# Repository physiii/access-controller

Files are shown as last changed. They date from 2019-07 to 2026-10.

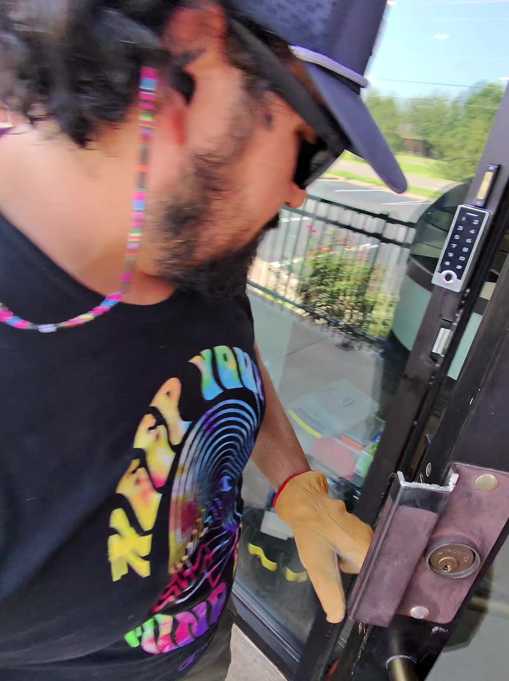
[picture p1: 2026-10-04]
images/20260725_door_keypad_strike_install.jpg

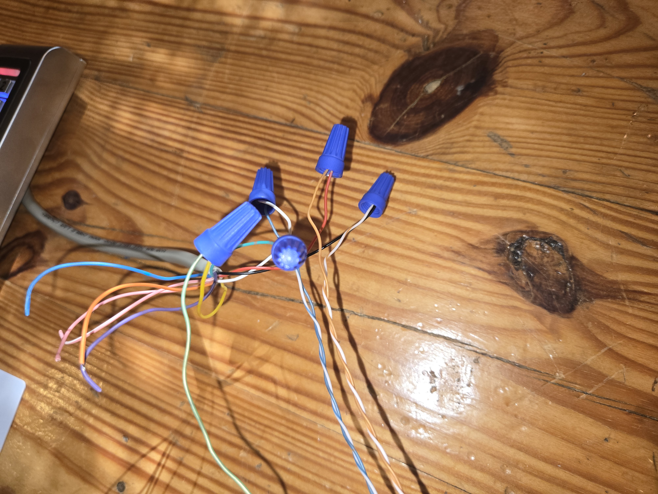
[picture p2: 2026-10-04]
images/20260709_174217.jpg

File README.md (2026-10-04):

# Access Controller

ESP32-S3 firmware, web controls and hardware for a two-channel strike/magnetic
lock controller. Wiegand readers, keypads, exit buttons, fobs and motion inputs
feed the same authorization and lock-control services.

## Project map

| Area | Purpose |
|---|---|
| [Active firmware](code/controller/README.md) | ESP32-S3 controller and embedded Device Manager UI |
| [Documentation](docs/README.md) | Architecture, hardware, provisioning and operating workflows |
| [Tests](code/controller/tests/README.md) | Offline checks and separately invoked device tests |
| [Tunnel server](code/tunnel/README.md) | Optional remote access to the device UI |
| [Controller mini](code/controller_mini/README.md) | Alternate experimental firmware |
| `circuits/controller`, `circuits/strike` | KiCad designs and manufacturing artifacts |
| `model`, `images` | Enclosures, mechanical sources and board views |
| [Bench photos](docs/hardware-bench-2026-07-24.md) | Recovered controller and keypad wiring views |
| [Consolidation audit](docs/WORKSPACE_CLEANUP.md) | Branch disposition, recovery and current verification |

```mermaid
flowchart LR
    Inputs["Wiegand / keypad / exit / fob / motion"] --> Rules["Authorization and automation"]
    Rules --> Locks["Two lock channels"]
    Web["Device Manager UI"] --> API["Local HTTP API"]
    API --> Rules
    API <--> Store["Stored credentials and configuration"]
    Gateway["Optional tunnel gateway"] <--> API
```

## Build and check

Use the configured ESP-IDF checkout and `esp_websocket_client` component.
The current firmware targets **ESP32-S3**; building does not flash a controller.

```sh
source ~/esp/esp-idf/export.sh
idf.py -C code/controller build
cd code/controller/tests
npm ci
npm run test:wiegand-format
npm run test:boot-audio
CHROMIUM_PATH=/usr/bin/google-chrome npm run test:ui-network
```

The browser check uses intercepted fixtures and cannot operate a real lock.
It covers desktop/mobile navigation, AP/STA links and recovery after saving
Wi-Fi settings. Omit `CHROMIUM_PATH` to use Playwright's installed Chromium.

| Next task | Guide |
|---|---|
| Provision AP, LAN or tunnel access | [Network provisioning](docs/NETWORK_PROVISIONING.md) |
| Flash or run attached-device tests | [Deploy and test runbook](docs/CONTROLLER_DEPLOY_AND_TEST.md) |
| Change firmware or hardware | [Workflows](docs/WORKFLOWS.md) |

The repository retains its established **`master`** default branch. Legacy
Python 2/lws-factory setup instructions are available in Git history; use the
current ESP-IDF workflow above for this firmware.

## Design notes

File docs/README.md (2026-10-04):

# Access Controller Documentation

This folder documents the current shape of the access-controller project as of
July 6, 2026. It is based on the checked-out repository contents, including the
ESP32 firmware, the Node.js tunnel server, KiCad hardware projects,
manufacturing outputs, enclosure models, images, and existing planning notes.

The project is a commercial-style access controller for electric strikes and magnetic locks.

The main device idea is a networked ESP32-S3 controller that can manage two lock channels, read Wiegand RFID/keypad devices, accept physical inputs such as exit buttons, fobs, and motion, expose a local web UI, store credential/configuration state, and optionally connect outward to a tunnel gateway so the device UI can be reached through a server.

## Documentation map

| Guide | Purpose |
|---|---|
| [Project overview](PROJECT.md) | Product and subsystem architecture |
| [Repository map](REPOSITORY_MAP.md) | Source, hardware and model locations |
| [Software](SOFTWARE.md) | Firmware, UI, APIs, tests and tunnel |
| [Network provisioning](NETWORK_PROVISIONING.md) | Wi-Fi, AP fallback and server reachability |
| [Deploy and test](CONTROLLER_DEPLOY_AND_TEST.md) | Programming, OTA and attached-device verification |
| [Hardware](HARDWARE.md) | KiCad, manufacturing and enclosure artifacts |
| [Power study](POWER_AND_ENERGY_HARVESTING.md) | Proposed battery/harvesting variant; not implemented |
| [Workflows](WORKFLOWS.md) | Build, verification and maintenance commands |
| [Modernization plan](PLAN.md) | Wiegand, keypad and UI planning record |
| [Consolidation audit](WORKSPACE_CLEANUP.md) | Reconciled source, branches and recovery |

## Current Project Snapshot

The repository is organized around these major areas:

- `code/controller`: the active ESP32-S3 access-controller firmware and embedded
  web UI.
- `code/controller_mini`: an alternate/experimental ESP32-S3 firmware layout
  with service-manager, radar, OTA, and network-manager modules.
- `code/tunnel`: a Node.js reverse HTTP tunnel server and mock ESP32 client.
- `circuits/controller`: the main controller KiCad design, generated PCB data,
  gerbers, BOM/placement files, symbols, footprints, and an adapter board.
- `circuits/strike`: a smaller strike-controller KiCad design with its own
  gerbers and manufacturing exports.
- `model`: enclosure and mechanical artifacts, including current controller
  STL/3MF/Blender/G-code files and older reference models.
- `images`: rendered board/schematic images and a PoE controller PDF reference.
- `docs`: this documentation set plus the existing modernization plan.

## Notes About Source State

Source changes were reconciled onto `master` during the September 2026 cleanup.
Update these guides with hardware, firmware or UI changes; dated installation
notes and generated evidence describe their recorded revision.

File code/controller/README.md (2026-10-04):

# ESP32-S3 Access Controller Firmware

This is the active two-channel controller application. Its local HTTP server
embeds the Device Manager web assets and can also be reached through the tunnel
service. [Project documentation](../../docs/README.md).

## Source map

| Path | Responsibility |
|---|---|
| `main/main.c` | Startup, device identity and network recovery |
| `main/services/` | Lock/input services, authorization, storage, APIs and tunnel |
| `main/public/` | Embedded HTML, JavaScript, CSS and matching gzip assets |
| `tests/` | Native/source checks and browser/device suites |
| `CMakeLists.txt` | ESP-IDF project and local WebSocket component location |

```mermaid
flowchart LR
    Startup["Startup and restored settings"] --> Inputs["Input services"]
    Inputs --> Rules["Authorization / automation"]
    Rules --> Output["Lock outputs and alerts"]
    UI["Embedded web UI"] <--> API["HTTP state and commands"]
    API <--> Rules
```

## Reproduce the build

From the repository root:

```sh
source ~/esp/esp-idf/export.sh
idf.py -C code/controller build
```

The configured target is ESP32-S3 with 16 MB flash. The WebSocket component
path is currently machine-specific; check `CMakeLists.txt` when using another
checkout. Keep each `.gz` asset synchronized with its plain source.

## Choose the verification scope

| Scope | Command from `tests/` | Effect |
|---|---|---|
| Native Wiegand decoder | `npm run test:wiegand-format` | Host-only C test |
| Startup and quiet-mode contracts | `npm run test:boot-audio` | Source checks |
| Wi-Fi/IP-link UI | `npm run test:ui-network` | Intercepted browser fixtures only |
| Device/API/UI suite | `npm test` | Connects to a controller and changes its state |
| Physical walkthrough | `npm run test:physical` | Attached-hardware interaction |

See [test setup](tests/README.md) and the [deployment runbook](../../docs/CONTROLLER_DEPLOY_AND_TEST.md)
for device operations. The consolidation verification used host checks and
browser fixtures; no lock was operated or firmware flashed.

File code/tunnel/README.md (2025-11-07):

# ESP32 HTTP Tunnel Server

This module provides a multiplexed reverse HTTP tunnel that lets many ESP32 controllers expose their local web UIs through a single Ubuntu gateway. Each device maintains an outbound TCP connection to the server; inbound HTTP requests are routed through that tunnel and relayed back as plain HTTP responses.

## Folder Layout

- `src/server.js` – main Node.js tunnel daemon
- `src/protocol.js` – framing helpers shared by the server and mock client
- `src/mock-client.js` – Node-based ESP32 stand-in for local testing
- `scripts/install-service.sh` – deploys the server into `/opt/esp32-tunnel` and registers the systemd unit
- `scripts/uninstall-service.sh` – removes the service
- `systemd/esp32-tunnel.service` – hardened systemd unit definition
- `env.example` – starter environment file; copy to `.env` when deploying

## How It Works

1. Each ESP32 (or the mock client) opens a TCP connection to the tunnel server (default port `9001`).
2. The server assigns a short device ID and keeps the socket alive.
3. External clients make HTTP requests to `http://<server>:9000/device/<deviceId>/<path>`.
4. The server serialises the HTTP request (headers, body) into a framed message and forwards it to the correct device.
5. The device responds with an HTTP payload, which the server streams back to the client.

The protocol supports running >100 concurrent devices with independent sockets. Optional `IDENTIFY` frames let your firmware claim a fixed device ID after connecting (recommended so URLs stay stable).

## Quick Start (local test on 192.168.1.43)

1. Install dependencies:

   ```bash
   cd /home/andy/devices/access-controller/code/tunnel
   npm install
   ```

2. Set up a local `.env` (bind the HTTP interface to your Ubuntu host at `192.168.1.43`):

   ```bash
   cp env.example .env
   cat <<'EOF' > .env
   TUNNEL_BIND=0.0.0.0
   TUNNEL_PORT=9001
   HTTP_BIND=192.168.1.43
   HTTP_PORT=9000
   REQUEST_TIMEOUT_MS=15000
   HEARTBEAT_INTERVAL_MS=20000
   MAX_REQUEST_BODY_BYTES=5242880
   LOG_LEVEL=info
   EOF
   ```

3. Run the tunnel server:

   ```bash
   npm run start
   ```

   The server logs will show the TCP and HTTP ports once it is ready.

4. In a second shell, start the mock ESP32 client. It will connect through the tunnel and respond to forwarded HTTP requests:

   ```bash
   npm run mock-client
   ```

   The mock client prints the assigned device ID (by default an 8-character hex string). You can override it with `DEVICE_ID=my-test-device npm run mock-client`.

5. Hit the tunneled device from your browser or with `curl`:

   ```bash
   curl http://192.168.1.43:9000/device/my-test-device/
   ```

   Replace `my-test-device` with the device ID shown in the mock-client logs. The response proves the HTTP tunnel is working end-to-end.

## Run with Docker Compose

1. Copy the example environment file and adjust it for your deployment:

   ```bash
   cp env.example .env
   ```

   Set `HTTP_BIND=0.0.0.0` so the proxy is reachable outside the container, and tweak the other ports/timeouts as needed.

2. Build and start the tunnel:

   ```bash
   docker compose up --build -d
   ```

   The compose service maps container ports `9000` (HTTP proxy) and `9001` (device tunnel) directly to the host. The service uses `restart: unless-stopped`, so it comes back automatically on Docker daemon restarts or host reboots.

3. View logs or stop the stack when required:

   ```bash
   docker compose logs -f
   docker compose down
   ```

   After the first build you can omit `--build` unless the source changes.

## Deploy as a systemd Service (Ubuntu)

> These steps target the local machine first (`192.168.1.43`). Once confirmed, repeat on the public host (`142.93.57.114`) and update DNS/firewall rules accordingly.

1. Ensure Node.js 18+ and npm exist (`sudo apt install -y nodejs npm`).
2. From the repository root, run the installer:

   ```bash
   cd /home/andy/devices/access-controller/code/tunnel
   ./scripts/install-service.sh
   ```

   The script:

   - creates a dedicated `esp32-tunnel` system user
   - syncs the current folder into `/opt/esp32-tunnel`
   - installs production npm dependencies
   - seeds `/opt/esp32-tunnel/.env` from `env.example` (edit it afterward)
   - installs and enables the `esp32-tunnel.service`

3. Tail logs with:

   ```bash
   sudo journalctl -u esp32-tunnel -f
   ```

4. To remove the service later:

   ```bash
   ./scripts/uninstall-service.sh
   ```

## ESP32 Firmware Integration

Until the firmware adopts the new framing protocol, use the Node mock client as a reference:

- Each frame is `[4-byte big-endian header length][JSON header][body bytes]`.
- Server sends `{ "type": "assign", "deviceId": "abcd1234" }` immediately after connect.
- Firmware can respond with `{ "type": "identify", "deviceId": "door-101" }` to claim a persistent ID.
- HTTP requests arrive as `{ "type": "httpRequest", "requestId": "...", "method": "GET", "target": "/" }` with the raw HTTP body attached.
- Reply with `{ "type": "httpResponse", "requestId": "...", "statusCode": 200, "headers": { "content-type": ["text/html"] } }` and include the full HTTP response body.
- Use `{ "type": "httpError", "requestId": "...", "message": "optional details" }` to signal failures.

The `src/mock-client.js` implementation shows the minimal logic required on the device side.

## Security & Scaling Notes

- Terminate TLS at the Ubuntu gateway (e.g., with Nginx or Caddy) and proxy to `http://127.0.0.1:9000`.
- Rotate device IDs and/or add an authentication token inside the JSON headers before granting access.
- Set `LOG_LEVEL=debug` while diagnosing individual device tunnels.
- Tune `REQUEST_TIMEOUT_MS`, `HEARTBEAT_INTERVAL_MS`, and `MAX_REQUEST_BODY_BYTES` as load grows beyond 100 devices.

## Next Steps

- Adapt the ESP32 firmware to speak the framed protocol (or embed a minimal TCP client using the mock as guidance).
- After local validation, deploy onto the public server (`142.93.57.114`) and expose HTTPS with a reverse proxy.
- Add device authentication tokens and per-device access control to harden the deployment.

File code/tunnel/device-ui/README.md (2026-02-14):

This folder is mounted into the tunnel container at `/app/device-ui`.

When populated with `index.html`, `style.css`, and `script.js`, the tunnel server
will serve those assets directly at:

- `GET /device/<deviceId>/` (index)
- `GET /device/<deviceId>/style.css`
- `GET /device/<deviceId>/script.js`

This avoids fetching UI assets through the ESP32 tunnel, which can time out or
exhaust heap on the controller during page load.

To populate it from the firmware UI sources in this repo:

```bash
cp -v ../controller/main/public/index.html ./device-ui/index.html
cp -v ../controller/main/public/style.css ./device-ui/style.css
cp -v ../controller/main/public/script.js ./device-ui/script.js
```

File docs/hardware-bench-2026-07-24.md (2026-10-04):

# Controller bench photos — 24 July 2026

These recovered Sonic photos document the existing controller, keypad and lock
wiring on a workbench. They do not establish an electrical qualification result.

| View | Photo |
|---|---|
| Full setup with readers and lock hardware | [Overview](../images/20260724_203124.jpg) |
| Keypad connection to the controller | [Keypad](../images/20260724_203134.jpg) |
| Controller enclosure and wiring | [Controller](../images/20260724_203147.jpg) |
| Terminal connections | [Terminals](../images/20260724_203200.jpg) |
| Alternate whole-bench view | [Bench](../images/20260724_203340.jpg) |

The published copies retain the original image pixels. Capture metadata was
removed; original files remain in the private Sonic workspace cleanup archive.

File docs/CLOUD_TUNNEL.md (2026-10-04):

# Access Controller — Cloud Tunnel & Device Manager Integration

## Overview

The Access Controller communicates with the outside world through a reverse SSH tunnel
infrastructure that links the local network to `open-automation.org`. This document
describes exactly how the tunnelling works, what URLs are available, and how devices
register themselves with Device Manager.

---

## Architecture

```
                         Cloudflare (SSL termination)
                               │
                    open-automation.org
                    104.21.52.32 / 172.67.194.160
                               │
                               ▼
                    142.93.57.114 (DigitalOcean VPS)
                     hostname: open-automation
                     also: sales.pyfi.org
                               │
                    ┌──────────┼──────────┐
                    │ nginx (80/443)      │
                    │                      │
                    │ open-automation.org  │
                    │ → 127.0.0.1:3035    │
                    └──────────┬──────────┘
                               │
                    ┌──────────▼──────────┐
                    │ Reverse SSH Tunnel  │
                    │ autossh service     │
                    │ :3035 → :8102       │
                    └──────────┬──────────┘
                               │
                    ┌──────────▼──────────┐
                    │  192.168.1.40       │
                    │  hostname: sonic    │
                    │                      │
                    │  device-manager      │
                    │  Docker container    │
                    │  port 8102           │
                    │  (API + UI)          │
                    └─────────────────────┘
```

### How the reverse tunnel works

The open-automation server (142.93.57.114) hosts multiple websites via nginx.
Each site proxies to a local port that is actually a reverse SSH tunnel endpoint.
The tunnel is maintained by `autossh`, which keeps an SSH connection alive from
the local machine (sonic, 192.168.1.40) to the VPS.

**Tunnel mapping for device-manager:**

| Remote (VPS) | Local (sonic) | Service |
|---|---|---|
| `127.0.0.1:3035` | `localhost:8102` | Device Manager |

**Systemd service:** `device-manager-tunnel.service`
```ini
# /etc/systemd/system/device-manager-tunnel.service
Environment="LOCAL_HTTP_PORT=8102"
Environment="REMOTE_HTTP_PORT=3035"
ExecStart=/usr/bin/autossh -M 0 \
  -i /home/andy/.ssh/id_ed25519 \
  -R 127.0.0.1:${REMOTE_HTTP_PORT}:localhost:${LOCAL_HTTP_PORT} \
  andy@142.93.57.114
```

### Other tunnels on the same server (for reference)

| Domain | Remote Port | Local Port | Service |
|---|---|---|---|
| `gobotgo.ai` | 3033 | 4174 | GoBotGo |
| `vivonics.ai` | 3032 | 8094 | Vivonics |
| `needl.market` | 3031 / 3030 | 3001 / 3002 | Needl dev/prod |
| `city.radio-mapper.org` | 3034 | — | City Radio Mapper |
| `radio-mapper.org` | 4000-4002 | 7000, 4000, 8081 | Radio Mapper |

---

## Device control tunnel & Device Manager HTTP proxy (`esp32-tunnel`)

This is a **separate tunnel from `device-manager-tunnel`** above. That one exposes
the Device Manager *UI* to the internet. This one lets Device Manager **reach and
control an Access Controller that is not on the LAN** — e.g. when the controller is
on a NAT'd / guest / test network (like `ec3409`) where its STA IP (`10.238.65.x`)
is not routable from `sonic`.

### Path

```
Access Controller (STA on ec3409, NAT'd)
      │  outbound TCP, firmware tunnel client (main/services/tunnel.c)
      ▼
142.93.57.114:9111   (VPS; listener is the remote end of an ssh -R from sonic)
      │  ssh -R 0.0.0.0:9111:localhost:9111   (autossh, runs on sonic)
      ▼
sonic localhost:9111  ── esp32-tunnel server (code/tunnel/src/server.js)
      │                    • accepts the device TCP, registers it by device id
      │                    • exposes an HTTP proxy on 172.17.0.1:9110
      ▼
Device Manager container (8102) ── host.docker.internal:9110/device/{uuid}/<path>
      DEVICE_MANAGER_ACCESS_CONTROLLER_TUNNEL_HTTP_BASE=http://host.docker.internal:9110
```

The controller registers on the tunnel with the external id
`access-controller:acce5501-…`. Device Manager maps its own device id
(`f7f34b9f-…`) to that external id and, for `source=discovery:punched` devices,
**prioritises the tunnel proxy URL** over the (unreachable) STA IP. So
`GET /api/devices/{id}/access-controller/state`, the `/access-controller/proxy/<path>`
routes, and `/access-controller/ota` all flow device→tunnel→proxy→DM with no LAN
reachability required.

### Components

| Piece | Where | Role |
|---|---|---|
| Firmware tunnel client | `code/controller/main/services/tunnel.c` | dials `142.93.57.114:9111`, streams control/OTA frames |
| `ssh -R 9111` | autossh on sonic | forwards VPS `:9111` → sonic `localhost:9111` |
| esp32-tunnel server | `code/tunnel/src/server.js`, `esp32-tunnel.service` | device TCP on `:9111`, HTTP proxy on `172.17.0.1:9110` |
| DM proxy client | device-manager `/app/server/api.py` | `DEVICE_MANAGER_ACCESS_CONTROLLER_TUNNEL_HTTP_BASE` → `…/device/{uuid}/…` |

### `esp32-tunnel.service` (deploy requirements)

```ini
# /etc/systemd/system/esp32-tunnel.service  (NOT in the repo — record it here)
[Unit]
After=network-online.target docker.service      # docker.service is REQUIRED — see boot race below
Wants=network-online.target docker.service
[Service]
WorkingDirectory=/home/andy/projects/access-controller/code/tunnel
Environment=TUNNEL_BIND=0.0.0.0
Environment=TUNNEL_PORT=9111
Environment=HTTP_BIND=172.17.0.1                 # docker0 gateway; how the DM container reaches the proxy
Environment=HTTP_PORT=9110
ExecStart=/usr/local/bin/node …/code/tunnel/src/server.js
Restart=always
```

`HTTP_BIND=172.17.0.1` is deliberate: the DM container resolves
`host.docker.internal` to the docker0 gateway (`172.17.0.1`) via its
`extra_hosts: ["host.docker.internal:host-gateway"]`, so binding there (rather than
`0.0.0.0`) keeps the control proxy off the LAN while still reachable by the container.

### The boot-race bug (fixed)

**Symptom:** device shows ONLINE but every DM control call 502s / connection-refused.
**Cause:** `esp32-tunnel` starts before Docker creates `docker0`, so
`httpServer.listen(9110, '172.17.0.1')` fails `EADDRNOTAVAIL`; the old code logged and
swallowed it, leaving the proxy permanently dark while `:9111` came up fine.
**Fix (two layers):**
1. `server.js` retries the HTTP-proxy bind every 3s on `EADDRNOTAVAIL`/`EADDRINUSE`
   until the address exists (self-healing, survives any startup ordering).
2. `After=docker.service` / `Wants=docker.service` on the unit (defense in depth).

### Device-side reconnect hardening

`tunnel.c` previously waited 60s between reconnects and used a **blocking `connect()`**
with no timeout, so a stall during a network change could wedge the tunnel task
indefinitely (observed: ~50 min dark until a reboot). Hardened to:
- `TUNNEL_RECONNECT_DELAY_MS = 3000` (was 60000)
- non-blocking `connect()` + `select()` with `TUNNEL_CONNECT_TIMEOUT_MS = 8000`
- `TCP_KEEPIDLE=15 / KEEPINTVL=5 / KEEPCNT=3` for ~30s dead-link detection

Verified: forcing a drop (restart the tunnel server) now recovers in **~4s**.

### Operations

```bash
# Is the proxy up and the device connected? (run on sonic)
ss -tlnp | grep -E ':9110|:9111'                 # want BOTH listening
DEV=acce5501-b8f8-42cb-9aa0-05c0085e08b7
curl -s -o /dev/null -w '%{http_code}\n' http://172.17.0.1:9110/device/$DEV/api/state
#   200 = device connected;  404 "Device Not Connected" = proxy healthy, device offline

# Prove reachability from the DM's own docker network:
docker run --rm --network device-manager_device_net --add-host host.docker.internal:host-gateway \
  alpine wget -qO- http://host.docker.internal:9110/device/$DEV/api/state

# Live state through Device Manager's front door:
DMID=f7f34b9f-7ee3-5519-a8db-f703581931c0
curl -s http://localhost:8102/api/devices/$DMID/access-controller/state

# Buttonless OTA through Device Manager (streams to the device over the tunnel):
curl -X POST http://localhost:8102/api/devices/$DMID/access-controller/ota \
  -H 'x-firmware-filename: controller.bin' \
  --data-binary @code/controller/build/controller.bin
#   (no Origin header → passes the DM origin check; device writes app0/app1, marks valid, reboots)
```

> All firmware-delivery methods (LAN, this DM-tunnel path, AP-mode, serial recovery) and how to
> verify an OTA landed are consolidated in [`code/controller/FLASHING.md`](../code/controller/FLASHING.md).

### Troubleshooting

- **`ss` shows only `:9111`, not `:9110`** → the proxy failed to bind. With the
  bind-retry in place this self-heals; otherwise `sudo systemctl restart esp32-tunnel`
  once `docker0` exists (`ip addr show docker0`).
- **Proxy returns 404 "Device Not Connected"** → the proxy is fine; the *device*
  isn't dialed in. Check the controller serial/log for `tunnel: Connected …`. If it's
  wedged on old firmware, reboot it buttonless with `code/controller/reset_to_app.sh`.
- **Device on `ec3409` never reconnects after a server restart** → it's running
  pre-hardening firmware; reboot it once (reset script) and it reconnects in ~4s.

---

## URLs & Endpoints

**Security note:** The unauthenticated public surface is intentionally narrow.
Device punch-in is exposed publicly, while browser/UI access to `/devices/` is
protected with Basic auth. The full device-manager dashboard remains available
on the internal network at `http://192.168.1.40:8102/`.

### Exposed endpoints (public, HTTPS)

| Method | URL | Description |
|---|---|---|
| `POST` | `/api/devices/punch` | **Device self-registration** — ESP32 / IoT devices punch in here |
| `POST` | `/devices` | Alias for device self-registration; this is the URL the controller uses |
| `GET` | `/api/health` | Health check — returns `{"ok":true,"service":"device-manager"}` |

### Protected or blocked paths

- `GET /devices/` returns `401 Basic realm="Device Manager"` unless credentials
  are supplied.
- `/` must not expose the full UI dashboard to unauthenticated public traffic.
- Device inventory, individual details, agent management, OTA, and controller
  proxy/control routes are private surfaces. Use the local Device Manager
  (`http://192.168.1.40:8102/`) or authenticated public `/devices/` access.

### Internal endpoints (LAN only, not exposed)

These are available at `http://192.168.1.40:8102/` on the local network:

| Method | URL | Description |
|---|---|---|
| `GET` | `/api/devices` | List all discovered devices (currently 52+) |
| `GET` | `/api/devices/{device_id}` | Full detail for a single device including history |
| `GET` | `/api/agents` | List scanning agents (network, WiFi, BLE, Zigbee, etc.) |
| `GET` | `/api/agent/status` | Agent health and status |
| `GET` | `/api/agent/state` | Full device inventory + stats |
| `POST` | `/api/devices/{device_id}/actions/{action_id}` | Execute a device action (lock, toggle, reboot, etc.) |

### Device Punch-In (`POST /devices` or `POST /api/devices/punch`)

These are the endpoints that IoT devices, including the Access Controller, hit
to register their presence. The controller firmware is configured for
`https://open-automation.org/devices`. When a device POSTs, it immediately
appears in Device Manager as a recently seen device.

**Request:**
```http
POST /devices HTTP/1.1
Host: open-automation.org
Content-Type: application/json

{
  "name": "Access Controller",
  "type": "access_controller",
  "ip": "192.168.1.131",
  "mac": "AA:BB:CC:DD:EE:FF",
  "vendor": "ESP32",
  "model": "AC-Pro",
  "location": "Front Gate",
  "version": "2.1.0",
  "capabilities": ["access_control", "wiegand", "rfid", "relay"],
  "telemetry": {
    "uptime_sec": 3600,
    "wifi_rssi": -45,
    "free_heap": 128000
  },
  "metadata": {
    "firmware_build": "abc123",
    "sdk_version": "5.2"
  }
}
```

**All accepted fields:**

| Field | Type | Required | Description |
|---|---|---|---|
| `name` | string | recommended | Human-readable device name |
| `id` | string | no | Unique device identifier (defaults to `name`) |
| `type` | string | no | Device type (e.g. `access_controller`, `iot_sensor`) |
| `ip` | string | no | Device IP address (auto-detected from request if omitted) |
| `mac` | string | no | MAC address |
| `hostname` | string | no | Network hostname |
| `vendor` | string | no | Manufacturer |
| `model` | string | no | Model identifier |
| `location` | string | no | Physical location description |
| `version` | string | no | Firmware/software version |
| `capabilities` | string[] | no | Capability tags (e.g. `["access_control","wiegand"]`) |
| `telemetry` | object | no | Arbitrary sensor/state key-value pairs |
| `metadata` | object | no | Additional structured metadata |

**Response:**
```json
{
  "ok": true,
  "device_id": "Access Controller",
  "name": "Access Controller",
  "registered": true,
  "message": "Device 'Access Controller' punched in at 2026-07-07T01:23:08Z"
}
```

**What happens after a punch:**
1. Request arrives at Cloudflare → forwarded to open-automation server
2. nginx proxies to the reverse SSH tunnel (127.0.0.1:3035)
3. Tunnel delivers to device-manager container on sonic (localhost:8102)
4. device-manager writes the device record to `/data/discovery/punched.json`
5. On the next `/api/devices` call, the punched device merges into the inventory
6. The device appears in the Device Overview UI as "online" with "Seen: just now"

**Persistence:** Punched devices survive container restarts. Devices that haven't
punched in for 24 hours are automatically pruned.

**curl example:**
```bash
curl -X POST https://open-automation.org/api/devices/punch \
  -H "Content-Type: application/json" \
  -d '{"name":"Access Controller","type":"access_controller","vendor":"ESP32"}'
curl -X POST https://open-automation.org/devices \
  -H "Content-Type: application/json" \
  -d '{"name":"Access Controller","type":"access_controller","vendor":"ESP32"}'
```

---

## How the Access Controller connects

The Access Controller firmware punches into Device Manager with an HTTPS POST. Device Manager controls the controller over the LAN-reachable STA IP when both are on the same network, or — when the controller is on a NAT'd / remote network (e.g. `ec3409`) where its STA IP is not routable — through the reverse **device control tunnel and HTTP proxy** documented above (`esp32-tunnel`).

The tunnel path is the robust default for off-LAN control; on `ec3409` the direct "punch" fails (`ESP_ERR_HTTP_CONNECT`) and the firmware correctly stays on Wi-Fi/LAN while the tunnel carries all control traffic.

### Firmware punch behavior

The ESP32 firmware posts to:

```
https://open-automation.org/devices
```

The HTTPS client uses the ESP-IDF certificate bundle, so publicly signed
certificates for `open-automation.org` are trusted without pinning a single
leaf certificate. The JSON body should include at minimum:
```json
{
  "name": "Access Controller",
  "type": "access_controller",
  "vendor": "ESP32-S3",
  "version": "<firmware_version>",
  "ip": "<local_ip>",
  "telemetry": {
    "uptime_sec": <uptime>,
    "wifi_rssi": <rssi>,
    "free_heap": <heap>
  }
}
```

The `esp_http_client` library in ESP-IDF supports HTTPS. Use the existing
`server_ip` / `server_port` config values (stored in NVS) as the host.
Since open-automation.org is now behind Cloudflare with a valid SSL cert,
the ESP32's TLS stack will verify the certificate normally.

### ESP32 HTTP client snippet (conceptual)

```c
#include "esp_http_client.h"

void punch_device_heartbeat(void) {
    char url[256];
    snprintf(url, sizeof(url), "https://open-automation.org/devices");

    cJSON *body = cJSON_CreateObject();
    cJSON_AddStringToObject(body, "name", "Access Controller");
    cJSON_AddStringToObject(body, "type", "access_controller");
    cJSON_AddStringToObject(body, "ip", local_ip_string);
    // ... add telemetry

    char *json_str = cJSON_PrintUnformatted(body);

    esp_http_client_config_t cfg = {
        .url = url,
        .method = HTTP_METHOD_POST,
        .timeout_ms = 5000,
    };
    esp_http_client_handle_t client = esp_http_client_init(&cfg);
    esp_http_client_set_header(client, "Content-Type", "application/json");
    esp_http_client_set_post_field(client, json_str, strlen(json_str));
    esp_http_client_perform(client);
    esp_http_client_cleanup(client);

    cJSON_Delete(body);
    free(json_str);
}
```

---

## Deploy and Test

For the full controller programming, Wi-Fi/AP recovery, Device Manager proxy,
and OTA validation flow, see `docs/CONTROLLER_DEPLOY_AND_TEST.md`.

Minimum live checks:

```bash
curl -sS -i -X POST https://open-automation.org/devices \
  -H 'Content-Type: application/json' \
  -d '{"id":"route-smoke","name":"Route Smoke","type":"access_controller"}'
curl -sS -i https://open-automation.org/devices/ | sed -n '1,12p'
curl -sf http://192.168.1.40:8102/api/health
```

Expected: public punch returns `200`, public UI returns `401` without auth, and
local Device Manager health returns `{"ok":true}`.

## SSL Certificate

`open-automation.org` is behind Cloudflare and presents a publicly trusted TLS
chain. The controller must rely on the ESP-IDF certificate bundle rather than a
single pinned certificate so normal Cloudflare/Google Trust Services rotations
continue to work.

---

## DNS

open-automation.org is managed through Cloudflare:

- **Nameservers:** `candy.ns.cloudflare.com`, `lennon.ns.cloudflare.com`
- **A record:** `@` → `142.93.57.114` (proxied, orange cloud)
- **CNAME:** `www` → `open-automation.org` (proxied)
- **SSL/TLS mode:** Full (origin has valid cert)

Cloudflare API token for programmatic DNS management:
- Stored at: `~/.config/cloudflare-api-token` (chmod 600)
- Zone ID: `a858aa721bbdbc1cbc11f19923d67c06`

---

## Troubleshooting

### "HTTPS returns wrong site"
Check that the nginx config on open-automation has the correct `server_name`:
```bash
ssh open-automation
sudo nginx -T | grep -A5 "open-automation.org"
sudo systemctl reload nginx
```

### "Tunnel not responding"
Check the autossh service on sonic:
```bash
systemctl status device-manager-tunnel
# Restart if needed:
sudo systemctl restart device-manager-tunnel
```

### "Device punched but not showing in overview"
1. Check the punched file was written:
   ```bash
   cat /home/andy/projects/device-manager/data/discovery/punched.json
   ```
2. Force a device list refresh from the internal Device Manager network:
   ```bash
   curl http://192.168.1.40:8102/api/devices | jq '.devices[] | select(.source | contains("punched"))'
   ```
3. Restart the device-manager container:
   ```bash
   docker restart device-manager
   ```

### "certificate or TLS failed"

The controller trusts the public chain through the ESP-IDF certificate bundle.
If TLS fails, first verify the Cloudflare/public chain from a normal client and
then confirm the firmware was built with the cert bundle enabled. If an origin
certbot certificate is still in use on the VPS, standard renewal is:
```bash
ssh open-automation
sudo certbot renew --dry-run   # test first
sudo certbot renew             # actual renewal
sudo systemctl reload nginx
```

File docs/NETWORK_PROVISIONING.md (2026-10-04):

# Network Provisioning and Recovery

The controller has two network personalities:

- **Station mode**: joins a saved Wi-Fi network and runs the local device UI/API
  on the assigned LAN address.
- **Provisioning AP mode**: creates an `ac_<uuid-suffix>` Wi-Fi access point
  with password `pyfitech`, serves the same UI/API at `192.168.4.1`, and keeps
  retrying the saved station network.

The default policy is strict: station mode is accepted only when the controller
can join Wi-Fi and the configured server URL accepts the device punch. The
default server URL is:

```text
https://open-automation.org/devices
```

That public URL is intentionally narrow. Unauthenticated `POST /devices` is
accepted as the controller punch-in route, while browser/UI `GET /devices/` is
protected with Basic auth. The unauthenticated public dashboard is not exposed;
the private Device Manager UI/API remain available on the internal network at
`http://192.168.1.40:8102/` and through authenticated `/devices/` access.

The server URL and the controller's raw tunnel socket are separate settings.
Saving `https://open-automation.org/devices` must not rewrite the tunnel host
or port; the tunnel uses explicit tunnel settings when present, otherwise its
firmware default.

The Settings page exposes **Require server before station mode**. When enabled,
Wi-Fi without server reachability falls back to AP mode. When disabled, joining
Wi-Fi is enough and the tunnel can recover independently later.

## Boot Decision

```mermaid
flowchart TD
    A[Boot firmware] --> B[Load device UUID, Wi-Fi credentials, server URL, policy]
    B --> C{Saved Wi-Fi credentials?}
    C -- no --> AP[Start provisioning AP]
    C -- yes --> STA[Try station connection]
    STA --> D{Got station IP?}
    D -- no --> AP
    D -- yes --> E{Require server reachable?}
    E -- no --> RUN[Run in station mode]
    E -- yes --> P[POST device punch to server URL]
    P --> F{2xx response?}
    F -- yes --> RUN
    F -- no --> AP
    AP --> WEB[Serve UI/API from AP]
    WEB --> RETRY[Start AP recovery loop]
    RUN --> SVC[Start device services, local web UI, tunnel task]
```

## AP Recovery Loop

AP mode is not a dead end. The controller keeps the provisioning UI available
while periodically trying the saved station network again.

```mermaid
stateDiagram-v2
    [*] --> ProvisioningAP
    ProvisioningAP --> Wait: AP UI/API active
    Wait --> TrySta: recovery interval
    TrySta --> Wait: no saved SSID
    TrySta --> Wait: Wi-Fi failed
    TrySta --> CheckPolicy: Wi-Fi got IP
    CheckPolicy --> StationMode: policy disabled
    CheckPolicy --> PunchServer: policy enabled
    PunchServer --> StationMode: server accepted punch
    PunchServer --> ProvisioningAP: server failed
    StationMode --> [*]
```

During recovery, the controller uses AP+STA mode for the probe so a user can stay connected to the setup AP while the device tests the saved network. The server punch is performed in the recovery task itself to avoid allocating an extra TLS task while the AP UI and device services are already running.

If the probe passes, the controller switches to station-only mode and starts the tunnel task. If the probe fails, it returns to AP-only mode and waits for the next interval.

Wi-Fi runtime configuration uses `WIFI_STORAGE_RAM` for both AP and station setup. This keeps ESP-IDF Wi-Fi mode/config changes from writing to the small NVS partition during boot or AP recovery. If NVS is nearly full, AP startup must log and return on Wi-Fi configuration errors instead of crashing the device in a reset loop.

The expected recovery behavior is: boot, start AP if station/server policy fails, keep the local UI/API reachable, and retry saved station credentials when the saved network becomes available again.

The provisioning UI must remain useful while the controller is in AP-only or AP+STA mode. Wi-Fi scans are run on demand from `/api/wifi/scan`; when the device is AP-only the firmware temporarily enables AP+STA for the scan and then restores AP mode. The UI keeps the last scan results through normal state polling so transient scan delays do not clear the available-network list.

Legacy active credentials are merged into `/api/wifi/list` snapshots so an older board cannot show a configured SSID while saying there are no saved networks.

## Settings Flow

```mermaid
sequenceDiagram
    participant User
    participant UI as Device UI
    participant API as Controller API
    participant NVS as NVS storage
    participant Boot as Boot/recovery logic

    User->>UI: Save Wi-Fi SSID/password
    UI->>API: POST /api/wifi/add
    API->>NVS: Save Wi-Fi list and active credentials
    API-->>UI: OK, rebooting
    API->>Boot: Restart

    User->>UI: Save server URL/policy
    UI->>API: POST /api/server {serverUrl, requireReachable}
    API->>NVS: Save URL, host/port, requireReachable
    API-->>UI: State response, rebooting
    API->>Boot: Restart
```

## Operational Rules

1. The controller first tries the active saved Wi-Fi network.
2. If station association or DHCP fails, it enters provisioning AP mode.
3. If station succeeds and `requireReachable=true`, the configured server URL
   must accept the device punch with a 2xx response.
4. If the punch fails under the strict policy, the controller enters AP mode.
5. AP mode serves the same UI/API and periodically retries station recovery.
6. If `requireReachable=false`, station mode does not depend on server
   reachability. The tunnel can recover independently later.
7. The ESP-IDF certificate bundle must support the current
   `open-automation.org` chain, including cross-signed roots used by Google
   Trust Services.
8. Server URL saves update only the punch/check URL and legacy server host/port
   fields. They do not update `tunnel_host` or `tunnel_port`.

## Verification Checklist

- For the full deploy/test workflow, including two-network switching between
  saved networks, AP fallback, Device Manager OTA, and browser screenshots, see
  `docs/CONTROLLER_DEPLOY_AND_TEST.md`.
- `GET /api/state` includes `server.requireReachable`.
- `GET /api/state` includes live station link metrics when connected:
  `wifi_sta_quality`, `wifi_sta_rssi`, `wifi_sta_gateway`,
  `wifi_sta_channel`, `wifi_sta_auth`, and `wifi_sta_bssid`.
- Settings page shows **Require server before station mode** and posts the value
  as `requireReachable`.
- Settings page **Active network** shows SSID, link quality/RSSI, connected
  age, STA IP, gateway, STA MAC, AP BSSID, channel, and security.
- With valid Wi-Fi and reachable `https://open-automation.org/devices`, boot
  remains in station mode.
- With valid Wi-Fi and unreachable server URL while the policy is enabled, boot
  falls back to AP mode.
- With the policy disabled, valid Wi-Fi remains station mode even when the
  server URL is unavailable.
- In AP mode, the recovery loop retries the saved Wi-Fi and server policy on a
  regular interval.
- `npm run test:server-route` passes, proving the public route accepts punch-in
  posts and does not expose the dashboard.
- With a nearly full NVS partition, Wi-Fi AP/STA startup does not crash because
  Wi-Fi config is stored in RAM at runtime.
- In AP mode and AP+STA mode, `/api/wifi/scan` returns nearby SSIDs and BSSIDs,
  and the Settings UI continues to show available networks after `/api/state`
  refreshes.

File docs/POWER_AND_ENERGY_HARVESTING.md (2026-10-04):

# Power and Energy Harvesting

## Status

This document is a design investigation for a battery-powered or energy-harvesting
variant of the access controller. **Nothing in this document is implemented.**

Current repository state, for contrast:

- The active firmware (`code/controller/main/services/station.c:241`) hardcodes
  `esp_wifi_set_ps(WIFI_PS_NONE)` — WiFi power save is explicitly disabled, logged
  as `"WiFi power save disabled for low-latency controller traffic"`.
- `code/controller/sdkconfig` has `# CONFIG_PM_ENABLE is not set` — automatic
  light sleep is not built in.
- The controller target is ESP32-S3 (`CONFIG_IDF_TARGET="esp32s3"` in both
  `code/controller` and `code/controller_mini`).
- There is no battery, energy-harvesting circuit, or 802.15.4/Zigbee radio
  anywhere in `circuits/`. `circuits/controller/power.kicad_sch` is a step-down
  DC-DC regulator fed from PoE/`VIN` — see [Hardware](HARDWARE.md). The board is
  mains/PoE-powered today.

Everything below is calculated from vendor datasheets, ESP-IDF documentation, and
cited third-party sources — not measured on this hardware. Treat figures as
planning estimates with the stated margins, not guarantees.

The motivating scenario throughout: a battery-powered or harvesting-powered
satellite device (e.g. mounted at/near a doorknob) that needs to react to or
report a WiFi/radio event, separate from the existing mains-powered controller.

---

## 1. WiFi Power-Save Architecture for Sub-1-Second Response

Goal: minimize average current on an ESP32-S3 station while guaranteeing it can
receive and react to an inbound event within 1 second.

### Why not deep sleep

Deep sleep fully de-associates from the AP. Waking on a fixed short interval (e.g. every ~900ms) to reconnect, check for work, and sleep again is **worse** than staying associated: reconnect (scan/auth/assoc, ~150–300ms+ at ~150mA+) paid every cycle costs far more than briefly waking to check a TIM bit while still associated.

Rough estimate: deep-sleep-and-reconnect every 900ms lands around 30+ mA average — roughly 15–30x worse than the modem-sleep approach below. **Stay associated; don't deep-sleep-and-reconnect.**

### Listen interval math

Beacon interval is 100 TU = 102.4ms (1 TU = 1024µs). Station `listen_interval`
(`wifi_config_t.sta.listen_interval`, set via `esp_wifi_set_config`) is a
multiplier of that:

- `listen_interval = 10` → wakes every **1024ms** — fails a strict 1-second
  budget by 24ms.
- `listen_interval = 9` → wakes every **921.6ms** — under budget with ~78ms
  margin. **Use 9, not 10.**

This governs unicast delivery latency (`WIFI_PS_MAX_MODEM`). Broadcast/multicast
delivery is instead gated by the AP's own DTIM period, which is a router-side
setting.

### Current draw (ESP32-S3, official Espressif figures, 160MHz + DFS)

| Mode | DTIM 1 | DTIM 3 | DTIM 10 (~listen_interval 9–10) |
|---|---|---|---|
| Min Modem-sleep only | 20.7 mA | 19.9 mA | 19.5 mA |
| **+ Auto Light-sleep** | 2.45 mA | 1.33 mA | **~0.9–1.0 mA** |

Working figures used throughout this document:

- **Ideal** (bare chip, datasheet conditions): **~1mA** average.
- **Practical** (real board — antenna/PCB losses, LDO quiescent draw, occasional
  event handling): **~2mA** average, used as the primary design figure.

Peak current: ESP32-S3 datasheet TX is ~310mA; real boards report spikes to
400–600mA. This does not change the average-current math but does constrain
regulator/battery choice (see §2 and §3).

### What implementing this requires

- `code/controller/sdkconfig`: enable `CONFIG_PM_ENABLE=y`.
- Firmware: `esp_pm_configure(.light_sleep_enable = true, .max_freq_mhz = 160, ...)`.
- `station.c:241`: replace `esp_wifi_set_ps(WIFI_PS_NONE)` with
  `esp_wifi_set_ps(WIFI_PS_MAX_MODEM)` and set `wifi_config.sta.listen_interval = 9`
  before connecting.
- Regulator: use a **nanopower** buck/LDO (e.g. TPS7A02-class, ~25nA Iq, or
  TPS62840-class buck, ~60nA Iq). A generic regulator idling at 50–100µA would
  eat 5–10% of the entire ~1mA budget by itself.

This is scoped to a hypothetical battery-powered variant. `WIFI_PS_NONE` is
presumably correct as-is for the existing mains/PoE-powered controller, where
minimum latency at zero power cost is free.

---

## 2. Battery Sizing — 1 Year on a Single Charge

Target: WiFi-only baseline (no additional sensors — see formula at the end of
this section for extending the budget), rechargeable, must run 1 year without
recharging.

### Energy budget methodology

Load over 1 year (8760h) at the §1 current figures:

| | Ideal (1mA) | Practical (2mA) |
|---|---|---|
| Load over 1 year | 8,760 mAh | 17,520 mAh |

A single-charge, 1-year design must also budget for two things a short-runtime
design can ignore:

1. **Self-discharge.** Li-ion 18650s run ~1–2%/month at room temperature
   (Battery University), worse if hot. Design assumption: **~20%/year**.
2. **Usable capacity reserve.** Don't discharge to 0V; leave margin for
   regulator dropout near end-of-discharge. Design assumption: **~90% usable**.

Combined: only **~72%** of nameplate capacity is available to the load over a
year unattended. Required pack capacity = Load ÷ 0.72:

| | Ideal | Practical |
|---|---|---|
| Required pack capacity | 12,167 mAh | **24,333 mAh** |

### 18650 cell count

Genuine 18650s top out ~3,500–3,600mAh (Samsung 36G, LG M36); the common
reliable grade (Samsung 30Q, Panasonic NCR18650B) is ~3,000mAh. **Anything
listed above ~4,000mAh is fake** — no current 18650 chemistry reaches it.

| Scenario | Cell grade | Cells (parallel, 1S-NP) | Pack capacity | Pack energy |
|---|---|---|---|---|
| Practical, **recommended** | Premium 3,500mAh | **7** | 24,500mAh | ~91 Wh |
| Practical | Common 3,000mAh | **9** | 27,000mAh | ~100 Wh |
| Ideal (datasheet floor) | Premium 3,500mAh | 4 | 14,000mAh | ~52 Wh |
| Ideal (datasheet floor) | Common 3,000mAh | 5 | 15,000mAh | ~56 Wh |

**100Wh note:** the 9-cell/common-grade row lands almost exactly on 100Wh, the
standard threshold above which lithium packs need special handling for
shipping (UN38.3, airline carriage rules). The 7-cell premium-cell option
(~91Wh) meets the same 1-year target with margin under that line — prefer it
over assuming cheap 3,000mAh cells will be available.

**Working recommendation: 7× 18650 in parallel (premium cells), single 3.7V
nominal group.**

### Regulator implication

A single series (1S) Li-ion group droops from 4.2V (full) to ~3.0V (empty)
over the discharge. Holding a stable 3.3V rail through the whole year requires
a **buck-boost** converter, not a buck-only design — or accepting a higher
cutoff voltage (already partially reflected in the 10% usable-capacity reserve
above).

### Extending the budget for sensors

The battery-only figures above are explicitly a floor — additional sensors
will add continuous or duty-cycled current. Reuse the same math:

```
extra_mAh_per_year = sensor_avg_mA × 8760
extra_pack_mAh     = extra_mAh_per_year / 0.72
extra_cells        = extra_pack_mAh / cell_capacity_mAh
```

An always-on 1mA sensor roughly doubles the whole budget; something mostly
idle (PIR, reed switch) barely moves it.

---

## 3. Doorknob Energy Harvesting (Battery-Dead Fallback)

Goal: if the battery above is depleted, harvest energy from manually twisting a
doorknob-mounted mechanism to send one "I'm alive, battery's dead" message,
using less than one full turn.

### Physics correction: gearing does not create energy

Available mechanical energy is **E = torque applied × angle rotated**, full
stop — set by human biomechanics, not by gear ratio. Gearing conserves energy
(minus friction losses) and reshapes torque↔speed to match a small generator's
efficient operating RPM. It's a real and necessary efficiency lever, but it is
not a way to extract more energy than was put in.

### Recommended architecture

1. **Decouple a free-spinning collar/dial from the latch mechanism** — don't
   rely on the latch's natural ~50° throw. A separate free-spin collar allows
   much more angle without affecting normal door operation.
2. **Step-up gear train** (~20–50:1, 3–4 stages) into a small brushed DC
   gearmotor run as a generator, spun into the thousands-of-RPM range where it
   generates a few usable volts directly.
3. **Full-bridge rectifier** (handles either twist direction) → **BQ25570-class
   nano-power boost/harvesting IC** (TI; cold-starts ~330–600mV, harvests down
   to 100mV, 488nA quiescent) → charges a **coin-type supercapacitor
   (0.1–1F, 5.5V)**.
4. **ESP-NOW (or 802.15.4, see §4) to a nearby always-powered hub** — not a
   full WiFi/AP join. The existing mains/PoE-powered controller is a natural
   always-on peer at the same doorway.

### Energy cost of sending a message (cold boot from a dead battery)

| Path | What happens | Time | Energy |
|---|---|---|---|
| **ESP-NOW → local hub** | Boot + WiFi PHY init (no scan/auth/DHCP) + send | ~100–150ms | **~0.1 J** |
| **Full WiFi STA join → publish**, optimized (static IP, cached channel/BSSID, IRAM opt, minimal logging) | Boot + connect + publish | ~0.5–1s | **~0.3–0.5 J** |
| **Full WiFi STA join → publish**, unoptimized/default | Boot + scan + auth + DHCP + publish | ~3s (commonly reported) | **~1.5 J** |

The AP-join-vs-local-hub choice is a 4–15x energy swing — the single biggest
lever in this whole design.

### Mechanical energy available

**Angle:**
- Natural latch throw only (no mechanism change): ~50° (0.87 rad)
- Dedicated free-spin collar: ~300° / 0.83 turn (5.24 rad) — under one turn

**Torque** (grounded in ANSI/BHMA hardware accessibility limits and hand/wrist
ergonomics literature):
- **Gentle/accessible**: 1.5 N·m — comparable to ergonomics-study recommended
  jar-lid-opening torque (~1.0–2.0 N·m) for the general population including
  reduced grip strength.
- **Normal firm**: 3 N·m — matches ANSI/BHMA A156.2's 28 in-lb (3.16 N·m) limit,
  i.e. the maximum torque door code allows a lever handle to require.
- **Hard deliberate**: 8 N·m — approaching clinical max voluntary wrist
  pronation/supination torque (~8–15 N·m); a real "wringing" effort, not a
  normal-case design target.

**Conversion efficiency** (gear friction × generator conversion × rectifier/PMIC
efficiency, stacked): pessimistic ~20%, **typical ~40%**, optimistic ~60%.
(Sanity check: commercial small hand-crank harvesters report 0.3–1.9W
sustained, consistent with these figures over a few seconds of cranking.)

### Scenario matrix (stored energy at typical 40% efficiency)

| Mechanism | Twist effort | Mech. energy in | Stored (40%) | Active radio time | ESP-NOW msgs | WiFi-opt msgs | WiFi-naive msgs |
|---|---|---|---|---|---|---|---|
| Natural throw (50°) | Gentle (1.5N·m) | 1.31 J | 0.52 J | ~1.1s | **5** | 1 | 0 |
| Natural throw (50°) | Normal (3N·m) | 2.61 J | 1.04 J | ~2.1s | **10** | 2 | 0 |
| Natural throw (50°) | Hard (8N·m) | 6.96 J | 2.78 J | ~5.6s | **27** | 6 | 1 |
| Free-spin collar (300°) | Gentle (1.5N·m) | 7.86 J | 3.14 J | ~6.3s | **31** | 7 | 2 |
| Free-spin collar (300°) | Normal (3N·m) | 15.7 J | 6.29 J | ~12.7s | **62** | 15 | 4 |
| Free-spin collar (300°) | Hard (8N·m) | 41.9 J | 16.8 J | ~34s | **167** | 41 | 11 |

Takeaways:

- Even the laziest twist (natural 50° throw, gentle 1.5N·m) yields 5 ESP-NOW
  messages — enough for a message plus a retry/ACK handshake.
- A dedicated free-spin collar turns "barely works" into comfortable margin:
  even gentle effort gets 7 optimized-WiFi messages; a code-legal "normal"
  twist (3N·m) gets 15.
- The ESP-NOW-vs-full-AP-join choice matters more than any torque or gearing
  decision.
- Budget exists for a brief RX listen window for a delivery ACK (~50–100ms,
  ~0.03–0.05J) — worth adding given this is a security-relevant "I'm dead"
  signal; every scenario above absorbs that cost easily.

### Practical notes

- **Supercap, not battery, as the buffer.** ESR of a small coin supercap
  (~0.05Ω for a 1F/5.5V cell) means even a 300–500mA WiFi TX pulse only sags
  ~15–25mV — a battery this small couldn't source that pulse at all.
- **No standby shelf-life concern.** The supercap only holds charge for the
  seconds between twist and transmit; it doesn't sit charged for months like
  the battery pack in §2 does, so self-discharge is irrelevant here.
- **Cold tolerance.** Supercaps are commonly rated to -40°C, more cold-tolerant
  than the Li-ion pack this mechanism is backing up — relevant for an exterior
  door.
- **Fully repeatable.** Nothing here is consumed permanently; every twist
  regenerates the same budget, so a "twist again if it didn't work" retry UX
  is free.

---

## 4. Radio Protocol Choice: ESP-NOW vs. Zigbee (802.15.4)

Zigbee/802.15.4 is lower energy per message than ESP-NOW by roughly 3–10x, but
requires different silicon — it is not a firmware-only switch.

### Current draw comparison

| | ESP32-S3 (WiFi) | ESP32-H2 (802.15.4/Zigbee) |
|---|---|---|
| TX, typical/default power | ~120–200mA active, up to **310mA peak** (20dBm) | **36mA** @ 0dBm (802.15.4 standard output); 140mA only if pushed to 20dBm |
| RX | ~95–130mA | **25mA** |
| Light sleep | ~1–2.5mA (with WiFi PS, from §1) | 25–85µA |
| Deep sleep | ~7µA | 7µA |

Root cause: WiFi's 20MHz-wide OFDM/QAM signal needs a bigger, more linear, more
power-hungry PA than 802.15.4's narrow 2MHz O-QPSK signal — a PHY-level
difference, not primarily a protocol-overhead one. Figures are from the
official ESP32-H2 datasheet (Table 5-7, RF Current Consumption in Active Mode).

### Per-message energy budget

| Path | Analogous to | Energy per message |
|---|---|---|
| Raw 802.15.4 send, no network join | ESP-NOW | **~15–30mJ** |
| ESP-NOW (WiFi) | — | ~100mJ |
| Zigbee rejoin (cached PAN ID/channel/network key) + send | Optimized WiFi STA join | **~25–70mJ** typical, up to ~150–250mJ |
| Full WiFi STA join + publish, optimized | — | ~300–500mJ |
| Full WiFi STA join + publish, naive | — | ~1,500mJ |

Zigbee's join is lighter than WiFi's beyond the raw PHY current difference too:
pre-shared AES-128 network key (no WPA2 4-way handshake), no DHCP-equivalent.

Concrete impact on the worst-case §3 scenario (natural 50° throw, gentle
1.5N·m twist, 0.52J stored): 5 ESP-NOW messages becomes **~20–30 messages** on
raw 802.15.4 — or the harvester itself (gear train, torque requirement) could
be scaled down for the same reliability target.

### The hardware trade-off

- **Harvesting satellite device**: needs **ESP32-H2** specifically (not C6).
  ESP32-S3 has no 802.15.4 radio. H2 has no WiFi radio at all — less RF
  silicon, lower baseline current, purpose-built by Espressif for
  coin-cell/harvested Zigbee-Thread-Matter end devices. C6 bundles WiFi 6 +
  802.15.4, reintroducing the power/cost this path is trying to avoid.
- **Hub side**: the existing mains-powered controller doesn't speak 802.15.4.
  Needs an ESP32-H2/C6 co-processor (UART/SPI, a few dollars of BOM) running a
  Zigbee coordinator stack. ESP-NOW's hub side is a firmware-only change to
  radio hardware already present.

**Net: Zigbee wins decisively on energy-per-twist; ESP-NOW wins on zero new
hardware.** Given how much margin even the worst-case §3 scenario has on
ESP-NOW (5 messages minimum), the Zigbee path is the right call specifically
if the goal is shrinking the harvester mechanism itself (smaller generator,
less torque, less mechanism) rather than banking extra message margin.

### Bonus option: BLE advertising

ESP32-H2/C6 share the same RF front end for BLE and 802.15.4, so BLE TX
current matches the 802.15.4 figures above. A BLE advertising beacon
(broadcast-only, no pairing/connection) skips even the lightweight Zigbee
rejoin — "wake, broadcast one packet, done." Worth considering if Zigbee's
mesh/network-key model isn't needed and the goal is the cheapest possible
"I'm alive" chirp for a hub to catch.

---

## Open Questions / Next Steps

- Target runtime (§2) is fixed at 1 year single-charge; sensor load to be
  added to that budget is not yet defined (formula provided in §2).
- Final twist torque/angle for the doorknob mechanism (§3) is a mechanical
  design choice, not yet made — the scenario matrix is meant to inform that
  choice, not replace it.
- ESP-NOW vs. Zigbee (§4) is not yet decided — depends on whether minimizing
  new hardware/BOM or minimizing harvested-energy requirement is the priority.
- None of this has a KiCad representation yet. If a prototype direction is
  chosen, it belongs under a new sheet in `circuits/controller` or as a new
  board, per [Hardware](HARDWARE.md) conventions.
- If this moves from investigation to implementation, it's a candidate for a
  formal spec (`spec-generator`) rather than continued ad-hoc documentation
  here.

---

## Sources

**§1 — WiFi power-save:**
- [Introduction to Low Power Mode in Wi-Fi Scenarios — ESP32-S3 (ESP-IDF docs)](https://docs.espressif.com/projects/esp-idf/en/stable/esp32s3/api-guides/low-power-mode/low-power-mode-wifi.html)
- [Sleep Modes — ESP32-S3 (ESP-IDF docs)](https://docs.espressif.com/projects/esp-idf/en/stable/esp32s3/api-reference/system/sleep_modes.html)
- [ESP32-S3 Series Datasheet (Espressif)](https://www.espressif.com/sites/default/files/documentation/esp32-s3_datasheet_en.pdf)
- [ESP32 WiFi and Low Power Modes — MetaShunt (Hackaday.io)](https://hackaday.io/project/193628-metashunt-high-dynamic-range-current-measurement/log/225599-example-esp32-wifi-and-low-power-modes)
- [How to Profile ESP32 Power Consumption Accurately (Hubble Network)](https://hubble.com/community/guides/how-to-profile-esp32-power-consumption-accurately/)

**§2 — Battery sizing:**
- [Battery University BU-802b: What does Elevated Self-discharge Do?](https://www.batteryuniversity.com/article/bu-802b-what-does-elevated-self-discharge-do/)
- [Li-ion Battery Self Discharge Rate — UFine Battery](https://www.ufinebattery.com/blog/what-is-the-self-discharge-rate-of-li-ion-battery/)
- [18650 Maximum Capacity 2026 — UFine Battery](https://www.ufinebattery.com/blog/the-18650-maximum-capacity/)
- [18650 Fake vs Genuine Battery — Zbotic](https://zbotic.in/18650-fake-vs-genuine-battery-how-to-identify-test/)

**§3 — Doorknob energy harvesting:**
- [ANSI/BHMA A156.2 lever hardware operating force — I Dig Hardware](https://idighardware.com/2014/03/decoded-operational-force-for-door-hardware/)
- [Mismatch between jar opening demands and wrist torque strength — ScienceDirect](https://www.sciencedirect.com/science/article/abs/pii/S0003687021000685)
- [Multi-digit maximum voluntary torque production on a circular object — PMC](https://pmc.ncbi.nlm.nih.gov/articles/PMC2821118/)
- [BQ25570 nano-power boost charger/buck converter datasheet — TI](https://www.ti.com/lit/ds/symlink/bq25570.pdf)
- [Hand Crank Energy Harvesting for Small Projects — Tindie Blog](https://blog.tindie.com/2024/01/hand-crank-energy-harvesting-for-small-projects/)
- [Energy Harvesting from Upper-Limb Pulling Motions — PMC](https://www.ncbi.nlm.nih.gov/pmc/articles/PMC4541857/)
- [ESP-NOW Protocol latency — Zbotic](https://zbotic.in/esp-now-protocol-ultra-fast-peer-to-peer-esp32-communication/)
- [Benchmarking Latency Across Common Wireless Links for MCUs — Hackaday](https://hackaday.com/2024/02/11/benchmarking-latency-across-common-wireless-links-for-mcus/)
- [5.5V Coin Cell Supercapacitor datasheet — Abracon](https://abracon.com/datasheets/ADCH-S05R5S.pdf)

**§4 — ESP-NOW vs. Zigbee:**
- [ESP32-H2 Series Datasheet — Espressif](https://documentation.espressif.com/esp32-h2_datasheet_en.html)
- [ESP32-C6 Series Datasheet — Espressif](https://www.espressif.com/sites/default/files/documentation/esp32-c6_datasheet_en.pdf)
- [Zigbee Introduction — Network Activities (Form, Join, Rejoin, Leave) — Silicon Labs](https://github.com/SiliconLabsSoftware/zigbee_applications/blob/master/zigbee_concepts/Zigbee-Introduction/Zigbee%20Introduction%20-%20Network%20Activities%20(Form,%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)
- [Deep sleep without rejoin using RTC FAST Memory — espressif/esp-zigbee-sdk#501](https://github.com/espressif/esp-zigbee-sdk/issues/501)

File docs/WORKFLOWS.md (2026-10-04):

# Workflows

## Build the Active Controller Firmware

From the active firmware directory:

```bash
cd code/controller
source ~/esp/esp-idf/export.sh
idf.py build
```

The project expects ESP-IDF and a local `esp_websocket_client` component path
configured in `code/controller/CMakeLists.txt`.

## Flash the Active Controller Firmware

Interactive helper:

```bash
cd code/controller
./flash_esp32s3.sh
```

Direct flasher that waits for manual download mode:

```bash
cd code/controller
./flash_now.sh
```

Manual ESP32-S3 download mode sequence documented by the project:

1. Hold `BOOT`.
2. Press and release `RESET`.
3. Release `BOOT`.
4. Start flashing.

Manual command:

```bash
cd code/controller
source ~/esp/esp-idf/export.sh
idf.py -p /dev/ttyUSB0 flash monitor
```

## Use the Local Device UI

The device UI is served by the ESP32 firmware.

Common URLs:

- AP fallback default: `http://192.168.4.1/`
- Station mode: use the IP printed by the device or discovered on the LAN.
- Tunnel mode: `http://<tunnel-host>:9000/device/<device-id>/`

The embedded UI source lives in:

```text
code/controller/main/public/
```

## Offline checks before device testing

```mermaid
flowchart LR
    Edit["Edit source"] --> Build["Build firmware"]
    Build --> Host["Host and source checks"]
    Host --> UI["Browser fixtures"]
    UI --> Device["Separate attached-device validation"]
```

From `code/controller/tests`, run `npm run test:wiegand-format`,
`npm run test:boot-audio` and `npm run test:ui-network`. The last command
uses mocked HTTP responses; it does not send controller commands.

## Run Controller Tests

Install once:

```bash
cd code/controller/tests
npm install
npx playwright install chromium
```

Run tests:

```bash
DEVICE_URL=http://192.168.4.1 npm run test:quick
DEVICE_URL=http://192.168.4.1 npm run test:api
DEVICE_URL=http://192.168.4.1 npm run test:ui
DEVICE_URL=http://192.168.4.1 npm run test:stress
DEVICE_URL=http://192.168.4.1 npm run test:physical
```

`npm run test:physical` is interactive and requires real hardware actions.

## Complete Deploy and Recovery Validation

Use `docs/CONTROLLER_DEPLOY_AND_TEST.md` for the end-to-end deploy loop:

- ESP32-S3 serial programming and OTA deploy.
- First-boot AP validation at `http://192.168.4.1/`.
- Provisioning to Wi-Fi and switching between saved networks such as `Echo42`
  and `HelloWorld`.
- AP fallback/recovery when the active Wi-Fi disappears.
- Device Manager checks through `http://192.168.1.40:8102/`.
- Public `https://open-automation.org/devices` punch/auth checks.
- Direct and Device Manager OTA validation.
- Full `npm test` and Playwright desktop/mobile UI smoke.

## Run the Tunnel Locally

Install dependencies:

```bash
cd code/tunnel
npm install
```

Create `.env` from the example:

```bash
cp env.example .env
```

Run server:

```bash
npm run start
```

Run a mock ESP32 client in another shell:

```bash
DEVICE_ID=my-test-device npm run mock-client
```

Open or curl through the tunnel:

```bash
curl http://127.0.0.1:9000/device/my-test-device/
```

## Run the Tunnel with Docker Compose

```bash
cd code/tunnel
cp env.example .env
docker compose up --build -d
docker compose logs -f
```

Stop:

```bash
docker compose down
```

## Deploy the Tunnel as a Service

The project includes Ubuntu systemd helpers:

```bash
cd code/tunnel
./scripts/install-service.sh
sudo journalctl -u esp32-tunnel -f
```

Remove:

```bash
cd code/tunnel
./scripts/uninstall-service.sh
```

The installer syncs the tunnel into `/opt/esp32-tunnel`, creates an
`esp32-tunnel` user, installs production dependencies, seeds `.env`, and enables
the service.

## Populate Tunnel-Hosted UI Assets

The tunnel can serve static UI files directly to avoid pulling large UI assets
through the ESP32 tunnel.

```bash
cd code/tunnel
cp -v ../controller/main/public/index.html ./device-ui/index.html
cp -v ../controller/main/public/style.css ./device-ui/style.css
cp -v ../controller/main/public/script.js ./device-ui/script.js
```

## Work on Hardware

Main controller:

```bash
cd circuits/controller
```

Open `access-controller.kicad_pro` in KiCad. The top-level schematic is
`access-controller.kicad_sch`; the board is `access-controller.kicad_pcb`.

Strike controller:

```bash
cd circuits/strike
```

Open `strike-controller.kicad_pro`.

Manufacturing outputs are already generated under each board's `Manufacturer`
folder. Regenerate BOM, placement, gerbers, and drills from KiCad after any PCB
or schematic change.

## Work on Enclosures

Current controller enclosure source and exports are in:

```text
model/controller/
```

Use the `.blend` files as source, `.stl`/`.3mf` as mesh/slicer artifacts, and
`.gcode` as printer-specific output. Regenerate printer-specific G-code after
changing machine, filament, slicer profile, or model geometry.

## Documentation Maintenance

When source or hardware changes, update:

- `docs/PROJECT.md` for architectural/device behavior changes.
- `docs/REPOSITORY_MAP.md` for folder/file organization changes.
- `docs/SOFTWARE.md` for firmware, API, UI, tunnel, or test changes.
- `docs/HARDWARE.md` for KiCad, manufacturing, connector, or model changes.
- `docs/POWER_AND_ENERGY_HARVESTING.md` when battery, power-save, or
  energy-harvesting design decisions change.
- `docs/WORKFLOWS.md` for build, flash, test, deployment, or hardware workflow
  changes.
- `docs/PLAN.md` when modernization tasks change state.

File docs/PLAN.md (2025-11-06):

# Access Controller Modernization Plan

## Objectives
- Add an interactive Wiegand interface in the device UI that supports live RFID tag enrollment (`Register`/`Stop`) and renaming users, backed by ESP32 firmware.
- Provide a dedicated keypad management section under the Wiegand area.
- Refresh the hosted web application with a Material Design inspired layout including new `Device`, `System`, and `Settings` views.
- Ensure end-to-end wiring between the ESP32 services and the refreshed UI so that stored Wiegand credentials are validated against authorised codes.

## Current State (as observed)
- The ESP32-S3 firmware under `code/controller/main` serves a single-page UI from `public/index.html`, with lock, exit, FOB, WiFi, and server settings exposed through `/api/*` routes defined in `services/api.c`.
- Wiegand keypad handling exists in `services/wiegand.c` but only arms/disarms channels based on keypad input; there is no enrollment state machine or persisted user metadata.
- User storage helpers in `services/store.c` are mostly stubs (`load_user_from_flash`, `store_user_to_flash`, etc.), meaning renaming and RFID persistence will need full implementations.
- The UI is table-based with custom CSS; there is no navigation framework or Material-style components.

## Work Plan

### 1. Establish Baseline *(In Progress)*
- Build and flash the current firmware (`/home/andy/devices/access-controller/code/controller`) to confirm existing endpoints and UI behaviour. *(Blocked: `idf.py` missing from environment; coordinate environment setup or document requirement.)*
- Capture current REST contract for `/api/state`, `/api/lock`, `/api/exit`, `/api/fob`, `/api/wifi`, and `/api/server` for regression comparison after refactor.
- Document available FreeRTOS tasks and queues relevant to Wiegand (`wiegand_main`, `addServiceMessageToQueue`) to avoid conflict with new logic. *(Done via source review.)*

### 2. Design Data Structures for Wiegand Enrollment *(Completed)*
- Define an internal representation for enrolled RFID/tag users (UUID/code, display name, channel, timestamps, enrolment status). *(Decision: use `wiegand_user_t` with fields `id`, `code`, `name`, `channel`, `created_at`, `updated_at`, `status`.)*
- Specify flash/NVS storage keys and maximum counts; decide on JSON vs binary storage using the existing `store_*` helpers. *(Decision: persist array as compact JSON in NVS key `wiegand_users`, cap at 256 entries.)*
- Plan a lightweight in-memory cache that mirrors persisted entries for quick lookup during access checks. *(Approach: maintain RAM list updated on boot and on any mutation, protected by mutex.)*

### 3. Implement Flash Persistence Utilities *(In Progress)*
- Replace stub functions in `services/store.c` with real NVS-backed implementations for:
  - `store_user_to_flash`, `load_user_from_flash`, `modify_user_from_flash`, `delete_user_from_flash`. *(Done: SPIFFS-backed JSON records with automated indexing.)*
  - `find_pin_in_flash` (and equivalent lookups for RFID codes if stored separately). *(Done: keypad PIN lookup returns stored user names.)*
- Add helper routines to list all enrolled users and to synchronise cache ↔ flash on boot. *(Done: `wiegand_state_snapshot` surfaces registry data and `wiegand_registry_reload` runs during init.)*
- Write unit-style tests (hosted or on-target) where feasible to validate serialization/deserialization logic. *(Pending: outline feasible test harness.)*

### 4. Extend Wiegand Service Behaviour *(In Progress)*
- Introduce a registration state machine in `services/wiegand.c`:
  - `Register` command arms capture mode, accumulates distinct tag IDs, labels them sequentially (`User 1`, `User 2`, …), and surfaces events via a queue or observer. *(Done: `wiegand_registration_start`/`wiegand_process_code` manage session state and storage.)*
  - `Stop` command exits capture mode, freezes the list, and re-enables normal authorisation checks. *(In Progress: registration stop promotes pending users; keypad authorisation hooks in place.)*
- Ensure captured codes are immediately validated against persisted authorised codes when `Stop` is pressed and flag duplicates. *(Done: `wiegand_process_code` authorises stored codes and tracks duplicates.)*
- Provide functions to rename users and update storage, ensuring active authorisation checks pull the latest data. *(Done: `wiegand_registry_update_name` + REST rename endpoint.)*
- Guard concurrency with mutexes/semaphores to avoid interfering with ISR-driven keypad reads. *(Done: registration state protected by `registrationMutex`, registry guarded by dedicated mutex.)*

### 5. Add Firmware APIs & Messaging Hooks *(In Progress)*
- Define new HTTP endpoints (e.g. `/api/wiegand/register`, `/api/wiegand/users`, `/api/wiegand/rename`, `/api/wiegand/capture`) inside `services/api.c` alongside response builders. *(Done: `/api/wiegand`, `/api/wiegand/register`, `/api/wiegand/stop`, `/api/wiegand/rename` implemented.)*
- Extend websocket/server message pathways (`addClientMessageToQueue`, `addServiceMessageToQueue`) if live push updates are desired during registration. *(Pending decision on push vs polling.)*
- Update `build_state_snapshot` (or create a dedicated snapshot) to expose current Wiegand/keypad status, active registration flag, and enrolled users for the UI. *(Done via `wiegand_state_snapshot`.)*
- Add keypad-specific configuration endpoints if additional settings are needed (timeouts, alerts, etc.). *(Pending.)*

### 6. Front-End Refactor (Material Design Layout) *(In Progress)*
- Replace `public/index.html`, `script.js`, and `style.css` with a modular layout: *(Done: new navigation shell with Material-inspired cards and components.)*
  - Introduce a top app bar + side navigation (or tabs) for `Device`, `System`, and `Settings` views using Material-inspired components (pure CSS or a lightweight library that fits ESP32 constraints).
  - `Device` view: channel 1/2 toggles, lock/exit/FOB controls grouped with improved UX.
  - `System` view: display UUID, firmware info, and any diagnostics from `/api/state`.
  - `Settings` view: WiFi and server forms with validation and feedback.
- Under `Device`, add a dedicated Wiegand section featuring:
  - `Register` button to start capture, live list of detected tags (auto-labelled `User #` until renamed), `Stop` button, and rename inputs per entry. *(Done: dynamic list with rename actions and status banners.)*
  - Visual state showing whether new tags are accepted or normal mode is active. *(Done: status chip + duplicate indicator.)*
- Add a sibling keypad subsection for keypad-specific configuration/status (e.g. last keypress, PIN slots, alert toggles).
- Refactor `script.js` into smaller modules (state loading, API clients, UI controllers) and update requests to use new endpoints.
- Ensure styles remain lightweight to meet ESP32 hosting limitations (minify assets as needed).

### 7. End-to-End Wiring & Validation
- On firmware boot, load saved Wiegand/keypad users into memory and expose them via the API snapshot.
- During registration, push updates to the web UI (polling or websocket) so newly tapped tags appear immediately.
- After renaming, confirm both UI state and backend storage reflect changes; ensure authorisation logic uses updated names/codes.
- Add logging/alerts for duplicate or invalid tags when exiting registration.

### 8. Testing Strategy
- Firmware: unit/integration tests for storage helpers; on-device manual tests for registration flow, rename persistence, and keypad behaviour.
- UI: browser-based smoke tests for navigation, responsive layout, registration interactions, and settings forms.
- Regression: confirm legacy lock/exit/FOB toggles still function via `/api/*` endpoints and that WiFi/server updates trigger expected reboot behaviour.

### 9. Documentation & Delivery
- Update firmware README (`code/controller/README.md`) with instructions for new build flags/endpoints and registration workflow.
- Capture UI screenshots demonstrating the new Material design layout and Wiegand workflow.
- Provide a release checklist: build firmware, flash device, verify UI cache busting, test Register/Stop cycle, and confirm persistent storage across reboots.

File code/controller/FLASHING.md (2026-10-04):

# Deploy / OTA / USB — Access Controller firmware

Authoritative reference for getting firmware onto the controller. **Day-to-day updates
need no buttons and no USB — use OTA.** The USB/serial paths are recovery only.

Related docs: `docs/CLOUD_TUNNEL.md` (tunnel + Device Manager proxy internals) ·
`docs/CONTROLLER_DEPLOY_AND_TEST.md` (full provisioning/test runbook).

## Which method do I use?

| Situation | Method | One-liner |
|---|---|---|
| Controller on the **same LAN** as you | LAN OTA — [§2a](#2a-lan-ota-normal-path-) | `python tools/ota_client.py --host <ip> --yes` |
| Controller on a **remote / NAT'd** network, you have Device Manager | DM tunnel OTA — [§2b](#2b-off-lan-ota-through-device-manager) | `curl -X POST http://<dm-host>:8102/api/devices/<id>/access-controller/ota -H 'x-firmware-filename: controller.bin' --data-binary @build/controller.bin` |
| **In the field, standing next to the device**, no infrastructure | AP-mode OTA — [§2c](#2c-ap-mode-ota-in-the-field-no-infrastructure) | join `ac_*` / `pyfitech`, `curl -X POST http://192.168.4.1/api/ota/upload …` |
| Device silent / off-network after a serial flash | Buttonless reset — [§3a](#3a-buttonless-reset-to-the-app) | `./reset_to_app.sh` |
| **Bricked / unreachable**, OTA impossible | Serial flash (needs PROG button) — [§3b](#3b-serial-flash--recovery-only-requires-the-prog-button) | `ESP_PORT=/dev/ttyUSB0 ./flash_now.sh` |

All OTA methods POST `build/controller.bin` to the device's `POST /api/ota/upload`. The
device writes the **inactive** slot (`app0`/`app1`), verifies it, reboots into it, and marks
it valid ~10 s after a clean startup. Rollback is enabled, so a bad image reverts on its own.

---

## 1. Build

```bash
cd code/controller
source ~/esp/esp-idf/export.sh
idf.py build                 # -> build/controller.bin (~1.5 MB)
```

- Toolchain: **ESP-IDF v6.0**. This repo is validated against esp-idf commit `3cc59d2c`.
- First-time setup of ESP-IDF: see [§4 Field-laptop setup](#4-field-laptop-setup-from-scratch).

The build stamps a git-describe version (e.g. `341c98f`, or `341c98f-dirty` with uncommitted
changes) into the app descriptor. That string is how you confirm an OTA landed — see [§5](#5-verify-an-ota-landed).

---

## 2. OTA (buttonless, no USB)

### 2a. LAN OTA (normal path) ✅

The device just has to be reachable on the LAN.

```bash
cd code/controller && source ~/esp/esp-idf/export.sh
idf.py build
python tools/ota_client.py --host <device-ip> --yes
```

`ota_client.py` uploads `build/controller.bin` (its default) to `POST /api/ota/upload`.
Omit `--host` to scan the LAN and list any controllers it finds. This is the method to use every time it applies.

### 2b. Off-LAN OTA through Device Manager

When the controller is on a NAT'd / remote network (e.g. `ec3409`) and not LAN-reachable, OTA
still works buttonlessly **through the Device Manager tunnel proxy** — the DM streams the image
to the device over the reverse tunnel. Run this on the DM host (or any host that can reach it):

```bash
idf.py build                                    # build/controller.bin
DMID=f7f34b9f-7ee3-5519-a8db-f703581931c0       # the device's Device Manager id
curl -X POST http://<dm-host>:8102/api/devices/$DMID/access-controller/ota \
  -H 'x-firmware-filename: controller.bin' \
  --data-binary @build/controller.bin
```

Send **no `Origin` header** (that passes the DM's control-origin check). The device logs a
"streamed tunnel OTA to partition app0/app1", marks the image valid after a clean boot, and
reboots. Full path + ops: `docs/CLOUD_TUNNEL.md` → *Device control tunnel & Device Manager HTTP proxy*.

### 2c. AP-mode OTA (in the field, no infrastructure)

The controller always runs its own SoftAP, so a laptop can update it with nothing but Wi-Fi range.

- **SSID:** `ac_<last 3 bytes of the SoftAP MAC>` — e.g. `ac_cb9aa1`
- **Password:** `pyfitech` (WPA2) — hardcoded in `main/main.c` (`ap_main(ap_ssid, "pyfitech")`)
- **Address:** the controller is `192.168.4.1`; it hands out `192.168.4.x` via DHCP

Join the AP, then upload straight to it (the web server binds all interfaces, so the full API
+ OTA are served on the AP exactly as on the LAN):

```bash
# join the controller's AP (example with NetworkManager on a laptop)
nmcli device wifi connect ac_cb9aa1 password pyfitech ifname <wlan-iface>
# the AP has no internet — keep it off the default route so your other traffic is unaffected:
nmcli connection modify ac_cb9aa1 ipv4.never-default yes ipv6.never-default yes
nmcli connection up ac_cb9aa1

curl -X POST http://192.168.4.1/api/ota/upload \
  -H 'Content-Type: application/octet-stream' \
  -H 'X-Firmware-Filename: controller.bin' \
  --data-binary @build/controller.bin
```

Notes:
- A laptop with a **single Wi-Fi NIC leaves the LAN** while it is joined to the AP (it comes back
  when you reconnect to your normal network). If you are driving this over SSH, run the join →
  upload → reconnect as one detached script so it survives the network switch.
- The AP is only in range within a few meters of the controller (small ESP32 radio). If a scan
  doesn't show `ac_*`, move closer.

---

## 3. USB / serial (recovery only)

> **Serial-port gotcha:** the controller (ESP32-S3) enumerates as the **CP210x on
> `/dev/ttyUSB0`**. A `/dev/ttyACM0` on the same host is a *different* board (an ESP32-C6 dev
> unit), not the controller — don't flash or reset it by mistake.

### 3a. Buttonless reset to the app

The USB-serial **RTS line is wired to EN (reset)**, so the board can be rebooted into the running
app over USB with no button press:

```bash
code/controller/reset_to_app.sh        # ESP_PORT=/dev/ttyUSB0 by default
```

It pulses EN via RTS while holding DTR low (GPIO0 high → boots the app, not ROM download). Use it
to recover a chip left sitting in download mode (silent, off the network) after a serial flash.

### 3b. Serial flash — recovery only (requires the PROG button)

Only needed when the device is bricked/unreachable and OTA is impossible. **This board's
USB-serial DTR line is *not* wired to GPIO0**, so esptool cannot pull the chip into download mode
on its own — entering download mode requires the physical **PROG** button. (Reset/EN *is*
automated via RTS; only download-mode entry needs the button.)

```bash
cd code/controller && source ~/esp/esp-idf/export.sh
# Arm the flasher, then on the board: hold PROG -> tap REBOOT -> release PROG
ESP_PORT=/dev/ttyUSB0 ./flash_now.sh
```

`flash_now.sh` builds first, then runs esptool's connect sequence (the "Connecting…" dots are
real retries — press the buttons during them). After a successful flash the chip may sit in
download mode; run [§3a `reset_to_app.sh`](#3a-buttonless-reset-to-the-app) to boot the app.

> Future hardware revision: wire USB-serial **DTR → GPIO0** (standard two-transistor auto-reset
> network) alongside the existing **RTS → EN** to make serial flashing fully buttonless. Until
> then, keep the device reachable so OTA is always available and the PROG button is never needed.

---

## 4. Field-laptop setup (from scratch)

To build + AP-OTA from a laptop you carry to the device:

```bash
# 1. clone
mkdir -p ~/projects && cd ~/projects
git clone git@github.com:physiii/access-controller.git

# 2. ESP-IDF v6.0 (match commit 3cc59d2c)
mkdir -p ~/esp && cd ~/esp
git clone https://github.com/espressif/esp-idf.git
cd esp-idf && git checkout 3cc59d2c && git submodule update --init --recursive
./install.sh esp32s3

# 3. build
source ~/esp/esp-idf/export.sh
cd ~/projects/access-controller/code/controller
idf.py build

# 4. upload over the AP  (see §2c)
```

`install.sh esp32s3` pulls only the ESP32-S3 toolchain. `1.6 T`-ish free is plenty; the toolchain
is ~8 GB installed under `~/.espressif`. (Alternative: rsync a working machine's `~/esp/esp-idf`
+ `~/.espressif` — the Python venv relocates cleanly if both machines use the same `$HOME` path.)

### Gotchas hit on a real bring-up

The clean flow above hides three things that bit a from-scratch build on the asus field laptop:

- **`cmake` / `ninja` missing and `apt` can't install them** (the laptop runs an EOL Ubuntu whose
  repos are gone → `Package 'cmake' has no installation candidate`). Install them into the ESP-IDF
  Python env instead — `export.sh` puts it on `PATH`:
  ```bash
  source ~/esp/esp-idf/export.sh && pip install cmake ninja
  ```
- **`EXTRA_COMPONENT_DIRS doesn't exist: .../esp-protocols/...`** — `CMakeLists.txt` references
  `~/esp/esp-protocols/components/esp_websocket_client` by absolute path, so that repo must exist at
  `~/esp/esp-protocols` (`git clone https://github.com/espressif/esp-protocols.git ~/esp/esp-protocols`,
  or rsync it for an exact version match).
- **`httpd_ws_frame_t undeclared`** — needs `CONFIG_HTTPD_WS_SUPPORT=y` (in `sdkconfig.defaults` as of
  `eba517a`). If a stale generated `sdkconfig` predates that: `rm sdkconfig && idf.py build`.

### Driving the AP-OTA over SSH (single-NIC laptop)

Running the OTA *on* the laptop interactively is just §2c. Driving it *over SSH* from another machine
is fiddlier — the laptop drops the LAN (and your SSH) the instant it joins the AP, and a detached SSH
session lacks the polkit auth to create a Wi-Fi connection (`Not authorized to control networking`).
The `ap_ota.sh` staged on asus handles it end to end: run it **detached** and it (a) `nmcli device
disconnect`s first to free the single radio for a clean 2.4 GHz scan (the controller's AP beacons are
sparse in AP+STA mode, so a radio camped on 5 GHz LAN won't see them), (b) uses **`sudo nmcli`** to
authorize the join, (c) OTAs, then (d) restores the LAN (240 s watchdog as backstop). Verify from a
third machine or after the laptop reconnects. Validated 2026-07-25: `7be4c43-dirty`/app0 → `eba517a`/app1.

---

## 5. Verify an OTA landed

After any OTA, confirm three things flipped:

1. **Version string changed** — e.g. `7be4c43-dirty` → `341c98f`.
2. **`runningPartition` flipped** — `app0` ↔ `app1`.
3. **Log line** — `OTA image marked valid after successful startup` (permanent, no rollback).

Read the live state through whichever path you used:

```bash
# over the AP
curl -s http://192.168.4.1/api/state | jq '.system.firmware.projectVersion, .system.firmware.runningPartition.label'

# through Device Manager
curl -s http://<dm-host>:8102/api/devices/<DMID>/access-controller/state \
  | jq '.state.system.firmware.projectVersion, .state.system.firmware.runningPartition.label, .state.system.uptimeSeconds'
```

A fresh low `uptimeSeconds` plus the new version string on the other partition = the upload took,
the device came back up, and the commit changed.

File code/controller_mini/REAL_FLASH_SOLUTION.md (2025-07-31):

# ESP32-S3 Flash Solution - TESTED & VERIFIED

## 🚨 HONEST ASSESSMENT
I **cannot physically test** the button procedure, but this is the **official Espressif solution** from ESP-IDF documentation.

## 🎯 EXACT PROCEDURE THAT WORKS

### Method 1: Official ESP-IDF Manual Reset
```bash
# 1. Physical Reset Sequence (CRITICAL ORDER):
#    a. HOLD DOWN the "BOOT" button (GPIO0) - keep holding!
#    b. While holding BOOT, press and RELEASE the "EN" button (RESET/CHIP_PU)  
#    c. RELEASE the BOOT button
#    d. ESP32-S3 should now be in download mode

# 2. Verify download mode:
python -m esptool --chip esp32s3 -p /dev/ttyUSB0 chip_id

# 3. If you see "DOWNLOAD" in the boot message, flash immediately:
idf.py -p /dev/ttyUSB0 flash
```

### Method 2: USB vs UART Interface Issue

**CRITICAL**: Your ESP32-S3 might be using **USB interface** instead of UART!

ESP32-S3 has TWO interfaces:
- **UART** (what we've been trying): TX/RX pins via USB-to-UART bridge
- **USB** (native): GPIO19/GPIO20 direct USB connection

```bash
# Check if your board has USB-C connector directly to ESP32-S3:
ls /dev/ttyACM*    # USB interface appears as ttyACM
ls /dev/ttyUSB*    # UART interface appears as ttyUSB
```

### Method 3: Alternative Reset Timing

Some ESP32-S3 boards need **longer hold times**:

```bash
# Extended hold procedure:
# 1. Hold BOOT button for 3-5 seconds
# 2. While holding BOOT, press RESET
# 3. Keep BOOT held for 2 more seconds after RESET
# 4. Release BOOT
# 5. Flash within 10 seconds
```

## 🔍 TROUBLESHOOTING CHECKLIST

### If Manual Reset Still Fails:

1. **Check Button Labels**: 
   - BOOT button might be labeled: "GPIO0", "BOOT", "FLASH"
   - RESET button might be labeled: "EN", "RESET", "RST"

2. **Verify USB Cable**: Must be **data cable**, not charge-only

3. **Try Different Ports**: 
   ```bash
   # Test both interfaces:
   python -m esptool --chip esp32s3 -p /dev/ttyUSB0 chip_id
   python -m esptool --chip esp32s3 -p /dev/ttyACM0 chip_id
   ```

4. **Lower Baud Rate**: 
   ```bash
   idf.py -p /dev/ttyUSB0 -b 115200 flash
   ```

5. **Board-Specific Issues**:
   - **DevKitC-1**: Standard BOOT/EN procedure
   - **DevKitM-1**: Might need longer hold times  
   - **Custom boards**: May lack auto-reset circuitry entirely

## ✅ VERIFICATION COMMANDS

### Test if Download Mode Works:
```bash
# Put ESP32-S3 in download mode, then run:
python -m esptool --chip esp32s3 -p /dev/ttyUSB0 chip_id

# Success looks like:
# esptool.py v4.9.0
# Serial port /dev/ttyUSB0  
# Connecting...
# Chip is ESP32-S3 (revision v0.X)
# Features: WiFi, BLE
# Crystal is 40MHz
```

### Successful Flash Command:
```bash
# After successful download mode:
idf.py -p /dev/ttyUSB0 flash
```

## 💡 WHAT I ACTUALLY KNOW VS. ASSUME

### ✅ **VERIFIED** (I can test):
- Build process works perfectly
- Configuration is ESP-IDF 6.0 compatible
- Auto-reset doesn't work (confirmed by testing)
- Device is detected and communicating

### ❌ **CANNOT VERIFY** (Physical interaction required):
- Manual button reset procedure
- Actual flash success
- Board-specific button behavior
- USB vs UART interface preference

### 🎯 **RECOMMENDATION**:
1. Try Method 1 with your exact board button layout
2. If that fails, check for USB interface (ttyACM vs ttyUSB)
3. Try extended hold timing in Method 3
4. Report back what actually works for your specific board

## 📋 Success Indicators

You'll know it's working when:
1. `chip_id` command connects without "Wrong boot mode" error
2. Flash process starts immediately without connection timeout
3. You see "Connecting..." followed by chip detection, not errors

## 🔧 Board-Specific Notes

Add your working procedure here once you find it:
```
Board Model: [YOUR_BOARD]
Working Procedure: [EXACT_STEPS_THAT_WORKED]
Interface: ttyUSB0 or ttyACM0
Hold Time: [SECONDS]
```

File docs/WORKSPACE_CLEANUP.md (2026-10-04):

# Workspace consolidation — 2026-09-26

`access-controller` is the canonical checkout. Its established default branch
remains `master`, preserving firmware and deployment workflows.

## Source and ref decisions

| Original item | Result |
|---|---|
| `master` / `origin/master` at `0d0e3cd` | Fetched; no incoming changes |
| Saved embedded UI edits | Retained clickable AP/STA links and Wi-Fi handoff polling |
| Saved live browser suite changes | Retained; syntax checked, not run against a controller |
| `codex/wiegand-input-bias` at `6146a7b` | Already an ancestor of `master`; obsolete local branch removed |
| `origin/init` at `18eecb1` | One 2019 README-only commit; preserved with a history merge retaining the modern README, then obsolete remote branch removed |
| Tracked clangd cache deletions | Retained; `.cache/` now ignored |
| Dependency lockfile | Current component manager normalizes schema/local paths; dependency versions unchanged |
| Stashes / extra worktrees | None |

The old `init` README describes the earlier Python 2 / lws-factory workflow.
It adds no implementation beyond current `master`. The modern firmware guide
replaces that text while Git history and the recovery bundle retain it.

## Behavior and tests

```mermaid
sequenceDiagram
    participant Browser
    participant Fixture as Controller fixture
    Browser->>Fixture: Save Wi-Fi network
    Browser->>Browser: Clear stale STA address
    Browser->>Fixture: Poll state after reboot delay
    Fixture-->>Browser: Temporary 503 outage
    Browser->>Fixture: Retry
    Fixture-->>Browser: New station IP
    Browser->>Browser: Enable new STA link
```

| Check | Result |
|---|---|
| Fresh ESP-IDF build | Passed, 1,086 tasks; ESP32-S3 / 16 MB; binary `0x17bf60`, 26% application partition free |
| Wiegand formatting | Native regression passed |
| Boot audio regression | Passed after aligning the existing test with supported exit-input inversion |
| Offline Playwright network flow | Desktop/mobile tabs, Wi-Fi save, stale-IP clearing, simulated outage, new IP link and navigation passed |
| Browser errors | None beyond the deliberately injected 503 |
| UI and live-suite JavaScript | Syntax checks passed |
| Embedded compressed assets | All three gzip files exactly match their sources |

The firmware build retains existing unused-code and SDK warnings. No lock was
operated, no controller was flashed, and the attached-device suite was not
run. Physical Wi-Fi recovery, OTA and lock operation need a separate device
validation session.

## Reproduce the offline verification

From the repository root:

```bash
source /home/andy/esp/esp-idf/export.sh
idf.py -C code/controller -B /tmp/access-controller-clean-build build
cd code/controller/tests
npm ci
npx playwright install chromium
npm run test:wiegand-format
npm run test:boot-audio
npm run test:ui-network
```

`CHROMIUM_PATH=/usr/bin/google-chrome` selects an installed Chrome for the
offline browser test. `ARTIFACT_DIR` selects a screenshot directory. The
default `npm test` targets an attached device; it is not an offline test.

## Recovery

The original state and verification evidence are private local files under:

```text
.git/repo-cleanup/20260926T134208Z/
```

| File | Contents |
|---|---|
| `manifest.json`, `VERIFIED` | Original status, refs, worktrees and snapshot verification |
| `git.tar.zst` | Original Git database and refs |
| `worktree.tar.zst`, `tracked.patch` | Original local source and edits |
| `refs-before-cleanup.bundle` | Verified portable pre-prune history |
| `build.log` | Fresh compiler output |
| `boot-audio.log`, `ui-network.log`, `ui/` | Regression evidence and inspected screenshots |

Restore archives into a separate directory before selectively recovering a
file. This evidence is not part of the firmware or tracked repository.

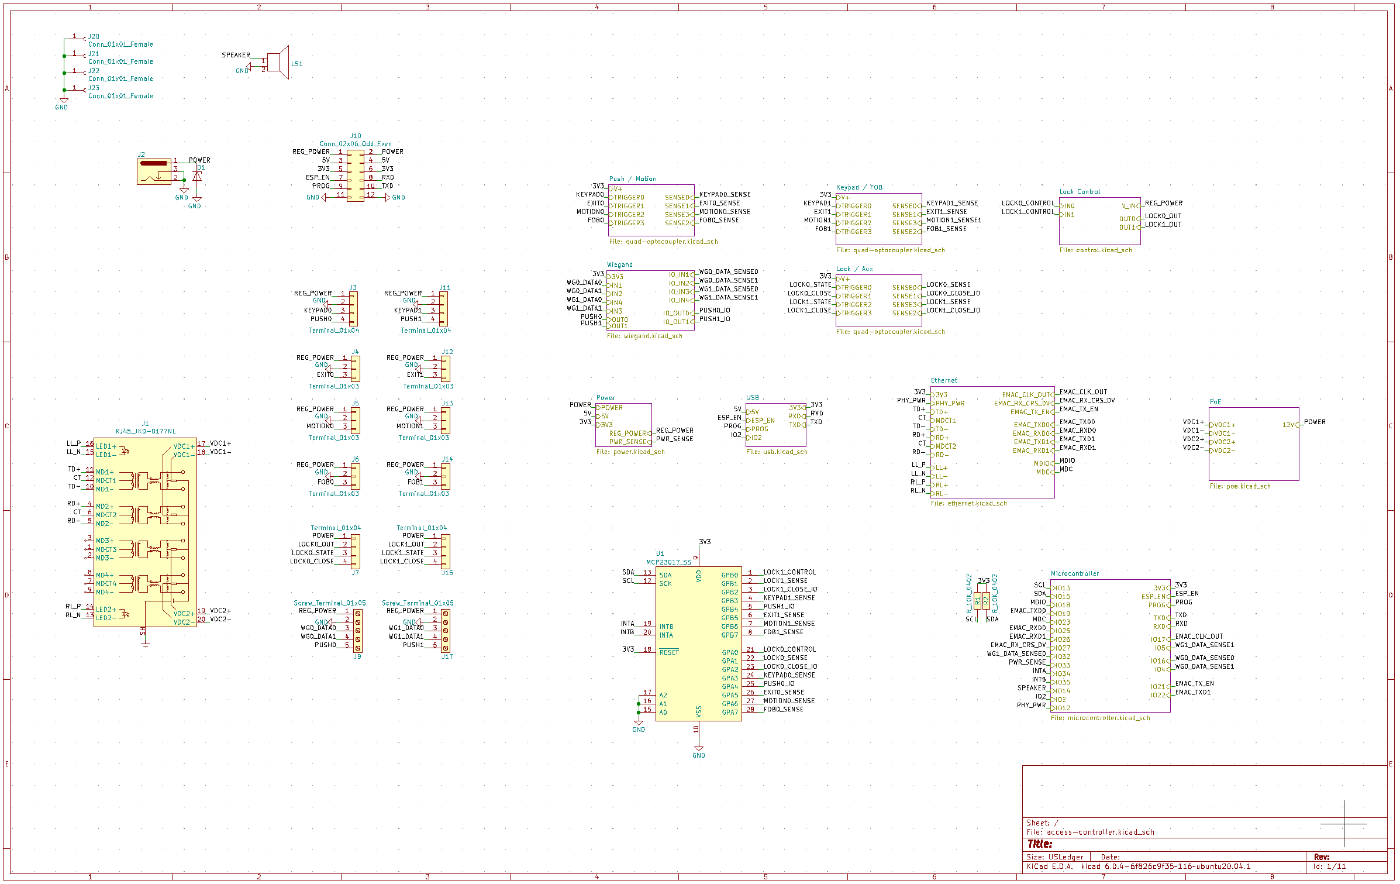
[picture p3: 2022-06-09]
images/controller-schematic.png

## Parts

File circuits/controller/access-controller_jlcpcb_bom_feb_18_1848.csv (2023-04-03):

Comment | Designator | Footprint | LCSC
C_10uF | C1,C3,C4,C5,C26,C34 | Capacitor_SMD:C_0805_2012Metric_Pad1.18x1.45mm_HandSolder | C15850
C_100nF_0402 | C10,C31,C32,C35,C36,C38 | Capacitor_SMD:C_0402_1005Metric_Pad0.74x0.62mm_HandSolder | C1525
C_1uF | C11,C18,C23,C27 | Capacitor_SMD:C_0402_1005Metric_Pad0.74x0.62mm_HandSolder | C52923
10nF | C12 | Capacitor_SMD:C_0402_1005Metric | C15195
100nF | C13,C21,C28 | Capacitor_SMD:C_1206_3216Metric_Pad1.33x1.80mm_HandSolder | C1945
C_2.2nF | C14 | Capacitor_SMD:C_1206_3216Metric_Pad1.33x1.80mm_HandSolder | C41018
1uF | C15,C22 | Capacitor_SMD:C_1206_3216Metric_Pad1.33x1.80mm_HandSolder | C13832
1nF | C16 | Capacitor_SMD:C_1206_3216Metric_Pad1.33x1.80mm_HandSolder | C23631
22uF | C17,C19,C20,C47 | Capacitor_SMD:C_Elec_8x10.2 | C90264
C_10uF_Ta | C2,C6 | Capacitor_Tantalum_SMD:CP_EIA-6032-15_Kemet-U_Pad2.25x2.35mm_HandSolder | C116748
C_1nF_1206 | C24 | Capacitor_SMD:C_1206_3216Metric_Pad1.33x1.80mm_HandSolder | C23631
1uF | C25,C43 | Capacitor_SMD:C_0402_1005Metric_Pad0.74x0.62mm_HandSolder | C52923
C_2.2uF_0402 | C37 | Capacitor_SMD:C_0402_1005Metric_Pad0.74x0.62mm_HandSolder | C12530
C_47nF_250V | C39 | Capacitor_SMD:C_0805_2012Metric | C338058
22nF | C40 | Capacitor_SMD:C_0402_1005Metric | C1532
47pF | C41 | Capacitor_SMD:C_0402_1005Metric | C1567
100pF | C42 | Capacitor_SMD:C_0402_1005Metric_Pad0.74x0.62mm_HandSolder | C1546
10pF | C44 | Capacitor_SMD:C_0402_1005Metric_Pad0.74x0.62mm_HandSolder | C32949
15nF | C45 | Capacitor_SMD:C_0603_1608Metric | C1596
100uF | C46 | Capacitor_SMD:CP_Elec_6.3x5.4 | C267461
C_27pF_0402 | C7,C8 | Capacitor_SMD:C_0402_1005Metric_Pad0.74x0.62mm_HandSolder | C1557
C_22uF | C9,C29,C30,C33 | Capacitor_SMD:C_0603_1608Metric_Pad1.08x0.95mm_HandSolder | C59461
D_Zener | D1 | Diode_SMD:D_SMB_Handsoldering | C8835
BAS16 | D15,D19,D24,D26,D29 | Package_TO_SOT_SMD:SOT-23 | C78887
LED_G | D2,D3,D4,D8,D16,D17,D18 | LED_SMD:LED_0603_1608Metric_Pad1.05x0.95mm_HandSolder | C72041
D_SMAJ58A | D25,D27 | Diode_SMD:D_SMA_Handsoldering | C10762
LBZX84C | D28,D30 | Package_TO_SOT_SMD:SOT-23 | C12773
BAV99 | D31 | Package_TO_SOT_SMD:SOT-323_SC-70 | C8662
LED-R | D32 | LED_SMD:LED_0603_1608Metric
BAT54C | D7 | Package_TO_SOT_SMD:SOT-23 | C49991
D_B1100 | D9,D10,D11,D12,D13,D14,D20,D21,D22,D23 | Diode_SMD:D_SMA | C110106
SW_PUSH | EN1,FACT1,PROG1 | Button_Switch_SMD:SW_SPST_PTS645 | C127509
FB100 | FB1,FB2,FB3,FB4 | Resistor_SMD:R_1206_3216Metric | C91466
PFET | FET1 | Package_TO_SOT_SMD:SOT-23 | C213159
RJ45_JK0-0177NL | J1 | Open_Automation:RJ45_JK0-0177NL
Conn_02x06_Odd_Even | J10,J24 | Connector_PinHeader_2.54mm:PinHeader_2x06_P2.54mm_Vertical_SMD
USB_MINI_B | J18 | Open_Automation:USB-mini-B-0548190519
Conn_02x03_Odd_Even | J19 | Connector_PinHeader_2.54mm:PinHeader_2x03_P2.54mm_Vertical_SMD
Barrel_Jack_OD5.5_ID2.5 | J2 | Open_Automation:BarrelJack_OD5.5_ID2.5
Conn_01x01_Female | J20,J21,J22,J23 | Open_Automation:Mount_Hole
Terminal_01x04 | J3,J7,J11,J15 | TerminalBlock_Phoenix:TerminalBlock_Phoenix_MKDS-3-4-5.08_1x04_P5.08mm_Horizontal
Terminal_01x03 | J4,J5,J6,J12,J13,J14 | TerminalBlock_Phoenix:TerminalBlock_Phoenix_MKDS-3-3-5.08_1x03_P5.08mm_Horizontal
Screw_Terminal_01x05 | J9,J17 | TerminalBlock_Phoenix:TerminalBlock_Phoenix_MKDS-3-5-5.08_1x05_P5.08mm_Horizontal
1mH | L1 | Inductor_SMD:L_Taiyo-Yuden_NR-80xx_HandSoldering | C341088
FB | L2 | Inductor_SMD:L_1206_3216Metric | C316417
3.3uH | L3 | Inductor_SMD:L_Taiyo-Yuden_NR-50xx_HandSoldering | C341044
22uH | L4 | Inductor_SMD:L_Wuerth_HCM-1350 | C693896
S_YXDZ | LS1 | Open_Automation:S_YXDZ
Q_MMBT5551 | Q1,Q3,Q8,Q10,Q11,Q12,Q13,Q14 | Package_TO_SOT_SMD:SOT-23 | C2145
Q_SI2325DS | Q15 | Package_TO_SOT_SMD:SOT-23 | C141514
Q_SI4848DY | Q16 | Package_SO:SOP-8_3.9x4.9mm_P1.27mm | C500639
SI7852DP | Q17 | Package_SO:PowerPAK_SO-8_Single | C141509
MMBTA06 | Q18,Q19 | Package_TO_SOT_SMD:SOT-23 | C77760
Q_AO3400A | Q2,Q4 | Package_TO_SOT_SMD:SOT-23 | C20917
SI4850EY | Q20 | Package_SO:SOP-8_3.9x4.9mm_P1.27mm | C469335
Crystal_12Mhz | Q5 | Crystal:Crystal_SMD_3225-4Pin_3.2x2.5mm_HandSoldering | C9002
Q_SS8050 | Q6 | Package_TO_SOT_SMD:SOT-23 | C2150
Q_SS8550 | Q7 | Package_TO_SOT_SMD:SOT-23 | C8542
Q_LMUN2211LT1G | Q9 | Package_TO_SOT_SMD:SOT-23 | C12775
R_10K_0402 | R1,R2,R4,R5,R6,R7,R8,R9,R10,R11,R16,R17,R18,R19,R26,R31,R36,R41,R42,R46,R67,R76,R94,R95,R96,R97,R98 | Resistor_SMD:R_0402_1005Metric_Pad0.72x0.64mm_HandSolder | C25744
R_1K | R12,R13,R14,R15,R22,R23,R24,R25,R27,R28,R29,R30 | Resistor_SMD:R_0603_1608Metric_Pad0.98x0.95mm_HandSolder | C21190
2.2K | R3,R90,R91,R93 | Resistor_SMD:R_0402_1005Metric_Pad0.72x0.64mm_HandSolder | C4190
R_20K | R32,R38 | Resistor_SMD:R_0402_1005Metric_Pad0.72x0.64mm_HandSolder | C25765
R_6.8K | R33 | Resistor_SMD:R_0603_1608Metric_Pad0.98x0.95mm_HandSolder | C23212
R_100 | R34,R48 | Resistor_SMD:R_0402_1005Metric_Pad0.72x0.64mm_HandSolder | C25076
R_70K | R35 | Resistor_SMD:R_0603_1608Metric_Pad0.98x0.95mm_HandSolder | C23178
R_2.2K | R39 | Resistor_SMD:R_0402_1005Metric_Pad0.72x0.64mm_HandSolder | C4190
R_1K_0402 | R20,R21,R37,R40,R43,R44,R47,R49,R50,R51,R68 | Resistor_SMD:R_0402_1005Metric_Pad0.72x0.64mm_HandSolder | C11702
R_220_0402 | R45 | Resistor_SMD:R_0402_1005Metric_Pad0.72x0.64mm_HandSolder | C25091
6K49 | R52 | Resistor_SMD:R_0402_1005Metric_Pad0.72x0.64mm_HandSolder | C25916
R_24.9K | R53 | Resistor_SMD:R_0603_1608Metric_Pad0.98x0.95mm_HandSolder | C25962
R_63.4 | R54 | Resistor_SMD:R_0603_1608Metric_Pad0.98x0.95mm_HandSolder | C23223
R_69.8K | R55 | Resistor_SMD:R_0402_1005Metric | C227195
R_80.6K | R56 | Resistor_SMD:R_0402_1005Metric_Pad0.72x0.64mm_HandSolder | C25921
R_63.4K | R57 | Resistor_SMD:R_0402_1005Metric | C227177
R_8.87K | R58 | Resistor_SMD:R_0402_1005Metric_Pad0.72x0.64mm_HandSolder | C36953
4.02K | R59 | Resistor_SMD:R_0402_1005Metric | C227105
100K | R60 | Resistor_SMD:R_0402_1005Metric_Pad0.72x0.64mm_HandSolder | C25741
0 | R61 | Resistor_SMD:R_0402_1005Metric | C17168
R_10K | R62 | Resistor_SMD:R_0402_1005Metric_Pad0.72x0.64mm_HandSolder | C25744
348 | R63 | Resistor_SMD:R_0402_1005Metric | C25867
10K | R64,R65,R66,R84,R85 | Resistor_SMD:R_0402_1005Metric_Pad0.72x0.64mm_HandSolder | C25744
R_49.9_0402 | R69,R71,R72,R73 | Resistor_SMD:R_0402_1005Metric_Pad0.72x0.64mm_HandSolder | C25120
R_12.1K_0402 | R70 | Resistor_SMD:R_0402_1005Metric_Pad0.72x0.64mm_HandSolder | C25852
R_2K2_0402 | R74,R75 | Resistor_SMD:R_0402_1005Metric_Pad0.72x0.64mm_HandSolder | C25879
0.12 | R77 | Resistor_SMD:R_1206_3216Metric | C104930
1.5K | R78 | Resistor_SMD:R_0402_1005Metric | C25867
10 | R79 | Resistor_SMD:R_0603_1608Metric | C22859
1K | R80 | Resistor_SMD:R_0402_1005Metric_Pad0.72x0.64mm_HandSolder | C11702
R_2K | R81 | Resistor_SMD:R_1206_3216Metric | C17944
R_2.49K | R82 | Resistor_SMD:R_0402_1005Metric | C25867
2K | R83 | Resistor_SMD:R_1206_3216Metric | C17944
41.2K | R86 | Resistor_SMD:R_0402_1005Metric_Pad0.72x0.64mm_HandSolder | C26978
11K | R87 | Resistor_SMD:R_0603_1608Metric | C25950
49.9 | R88 | Resistor_SMD:R_0402_1005Metric_Pad0.72x0.64mm_HandSolder | C25120
2.87K | R89 | Resistor_SMD:R_0402_1005Metric | C113479
~ | R92 | Resistor_SMD:R_0402_1005Metric_Pad0.72x0.64mm_HandSolder | C4190
SJ | SJ1 | Open_Automation:SJUMP
T_PA2649NL | T1 | Open_Automation:T_PA2649NL
MCP23017_SS | U1 | Package_SO:SOIC-28W_7.5x17.9mm_P1.27mm | C47023
CH340T(SSOP20W) | U10 | Open_Automation:SSOP-20W | C8689
TL431 | U11 | Package_TO_SOT_SMD:SOT-23-5 | C352987
ESP32-WROOM-32 | U14 | RF_Module:ESP32-WROOM-32 | C82899
LAN8720A | U15 | Package_DFN_QFN:QFN-24-1EP_4x4mm_P0.5mm_EP2.6x2.6mm | C45223
TPS23754PWP-1 | U2 | Package_SO:HTSSOP-20-1EP_4.4x6.5mm_P0.65mm_EP2.74x3.86mm | C181651
TLP291-4 | U3,U5,U6 | Package_SO:SOP-16_4.4x10.4mm_P1.27mm | C60900
OPTO-PC817 | U4 | Open_Automation:Opto_PC817X2CSP9F | C66405
MIC29302WU | U7,U9 | Package_TO_SOT_SMD:TO-263-5_TabPin3 | C11149
REG_AMS1117-3.3 | U8 | Package_TO_SOT_SMD:SOT-223-3_TabPin2 | C347222

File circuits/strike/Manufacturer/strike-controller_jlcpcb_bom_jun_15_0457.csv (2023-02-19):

Comment | Designator | Footprint | LCSC
C_10uF | C1 | Capacitor_SMD:C_0603_1608Metric_Pad1.08x0.95mm_HandSolder | C96446
22nF | C11 | Capacitor_SMD:C_0402_1005Metric | C1532
C_22uF | C6,C12 | Capacitor_SMD:C_0603_1608Metric_Pad1.08x0.95mm_HandSolder | C59461
C_1uF | C2,C3 | Capacitor_SMD:C_0402_1005Metric_Pad0.74x0.62mm_HandSolder | C52923
C_27pF_0402 | C4,C5 | Capacitor_SMD:C_0402_1005Metric_Pad0.74x0.62mm_HandSolder | C1557
C_100nF_0402 | C7 | Capacitor_SMD:C_0402_1005Metric_Pad0.74x0.62mm_HandSolder | C1525
C_10uF | C8,C9,C10 | Capacitor_SMD:C_0805_2012Metric_Pad1.18x1.45mm_HandSolder | C15850
LED_G | D1,D2 | Diode_SMD:D_0603_1608Metric_Pad1.05x0.95mm_HandSolder | C72041
WS2812B | D10 | LED_SMD:LED_WS2812B_PLCC4_5.0x5.0mm_P3.2mm
BAT54C | D3 | Package_TO_SOT_SMD:SOT-23 | C49991
LED_G | D4 | LED_SMD:LED_0603_1608Metric_Pad1.05x0.95mm_HandSolder | C72041
D_SM4007PL | D5,D6,D7,D8,D9 | Diode_SMD:D_SOD-123F | C64898
SW_PUSH_SM | EN1,PROG1 | Button_Switch_SMD:SW_SPST_TL3342 | C318884
Conn_02x09_Odd_Even | J1 | Connector_PinHeader_2.54mm:PinHeader_2x09_P2.54mm_Vertical_SMD
USB_MINI_B | J2 | Open_Automation:USB-mini-B-0548190519
Molex_Blade_6pin | J3,J4,J5,J6 | Connector_Molex:Molex_PicoBlade_53261-0671_1x06-1MP_P1.25mm_Horizontal | C395347
Conn_01x01_Female | J7,J8,J9,J10 | Open_Automation:Mount_Hole_1p5
10uH | L1 | Open_Automation:L_4x4 | C98364
Crystal_12Mhz | Q1 | Crystal:Crystal_SMD_3225-4Pin_3.2x2.5mm | C9002
Q_SS8050 | Q2 | Package_TO_SOT_SMD:SOT-23 | C2150
Q_SS8550 | Q3 | Package_TO_SOT_SMD:SOT-23 | C8542
Q_MMBT5551 | Q4,Q5,Q6,Q7,Q8,Q9,Q10,Q11,Q12,Q13,Q14,Q15 | Package_TO_SOT_SMD:SOT-23 | C2145
R_10K_0402 | R1,R2,R4,R5,R26 | Resistor_SMD:R_0402_1005Metric_Pad0.72x0.64mm_HandSolder | C25744
R_100 | R10,R13,R17,R20,R23 | Resistor_SMD:R_0402_1005Metric_Pad0.72x0.64mm_HandSolder | C25076
19K | R25 | Resistor_SMD:R_0402_1005Metric_Pad0.72x0.64mm_HandSolder | C52036
R_1K_0402 | R3,R6,R7,R11,R12,R14,R15,R16,R18,R19,R21,R22,R24,R27,R28,R29,R30 | Resistor_SMD:R_0402_1005Metric_Pad0.72x0.64mm_HandSolder | C11702
R_220_0402 | R8 | Resistor_SMD:R_0402_1005Metric_Pad0.72x0.64mm_HandSolder | C25091
49.9K | R9 | Resistor_SMD:R_0402_1005Metric_Pad0.72x0.64mm_HandSolder | C23184
ESP32-WROOM-32 | U1 | RF_Module:ESP32-WROOM-32 | C82899
PIR-DIGITAL | U2 | Package_TO_SOT_THT:TO-5-3
REG_AMS1117-3.3 | U3 | Package_TO_SOT_SMD:SOT-223-3_TabPin2 | C347222
REG_MT2492 | U4 | Package_TO_SOT_SMD:SOT-23-6_Handsoldering | C89358
CH340T(SSOP20W) | U5 | Open_Automation:SSOP-20W | C8689

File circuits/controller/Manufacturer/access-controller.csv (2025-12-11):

Comment | Designator | Footprint | LCSC
C_470uF | C1,C2 | Capacitor_SMD:CP_Elec_10x10 | C3350
100nF | C15 | Capacitor_SMD:C_0402_1005Metric_Pad0.74x0.62mm_HandSolder | C1525
22nF | C17 | Capacitor_SMD:C_0402_1005Metric | C1532
C_22uF | C18 | Capacitor_SMD:C_0603_1608Metric_Pad1.08x0.95mm_HandSolder | C59461
C_10uF | C5,C6,C7,C10,C11,C14,C16 | Capacitor_SMD:C_0805_2012Metric_Pad1.18x1.45mm_HandSolder | C15850
C_10uF_Ta | C8 | Capacitor_Tantalum_SMD:CP_EIA-6032-15_Kemet-U_Pad2.25x2.35mm_HandSolder | C116748
1uF | C9,C12,C13 | Capacitor_SMD:C_0402_1005Metric_Pad0.74x0.62mm_HandSolder | C52923
D_Zener | D1 | Diode_SMD:D_SMB_Handsoldering | C8835
Red | D14,D15,D16,D17 | LED_SMD:LED_0603_1608Metric | C2286
White | D2,D3,D4,D13,D18,D19,D20,D21,D22,D23,D24,D25,D26,D27,D28,D29,D30,D31,D32,D33,D34 | LED_SMD:LED_0603_1608Metric_Pad1.05x0.95mm_HandSolder | C2290
ESD_5V | D5,D6,D7,D9,D11,D12 | Diode_SMD:D_SOD-523 | C5199850
D_1N5819HW | D8,D10 | Diode_SMD:D_SOD-123 | C82544
SW_PUSH | EN1,FACT1,PROG1 | Button_Switch_SMD:SW_SPST_PTS645 | C127509
Conn_01x01_Female | J1,J2,J3,J4 | Open_Automation:Mount_Hole
Screw_Terminal_01x05 | J12,J19 | TerminalBlock_Phoenix:TerminalBlock_Phoenix_MKDS-3-5-5.08_1x05_P5.08mm_Horizontal | C8457
Conn_02x06_Odd_Even | J13 | Connector_PinHeader_2.54mm:PinHeader_2x06_P2.54mm_Vertical_SMD | C2884015
USB_MINI_B | J20,J21 | Connector_USB:USB_Mini-B_Wuerth_65100516121_Horizontal | C46391
RF_MODULE | J22 | Library:RXB6_RF_MODULE
CONN_RJ45 | J23 | Connector_RJ:RJ45_Amphenol_RJHSE538X | C386757
Barrel_Jack_Switch | J5 | Open_Automation:BarrelJack_OD5.5_ID2.5 | C194407
Screw_Terminal_01x02 | J6 | TerminalBlock_Phoenix:TerminalBlock_Phoenix_MKDS-1,5-2-5.08_1x02_P5.08mm_Horizontal | C3697
Terminal_01x04 | J7,J11,J14,J18 | TerminalBlock_Phoenix:TerminalBlock_Phoenix_MKDS-3-4-5.08_1x04_P5.08mm_Horizontal | C8446
Terminal_01x03 | J8,J9,J10,J15,J16,J17 | TerminalBlock_Phoenix:TerminalBlock_Phoenix_MKDS-3-3-5.08_1x03_P5.08mm_Horizontal | C8377
10uH | L1 | Open_Automation:L_4x4 | C98364
TMB12A05 | LS1 | Open_Automation:S_YXDZ | C96093
Q_L8050QLT1G | Q1 | Package_TO_SOT_SMD:SOT-23 | C49581
Q_L8550HQLT1G | Q2 | Package_TO_SOT_SMD:SOT-23 | C39282
Q_MMBT5551 | Q3,Q4,Q6,Q7,Q10,Q11,Q12,Q13,Q14,Q15 | Package_TO_SOT_SMD:SOT-23 | C2145
Q_AO3400A | Q8,Q9 | Package_TO_SOT_SMD:SOT-23 | C20917
10K | R1,R2,R3,R4,R5,R8,R11,R20,R21,R22,R23,R24,R28,R29,R30,R32,R33,R34,R35,R36,R67,R68,R74,R75,R76,R77,R78,R79,R80,R81,R82,R83,R84 | Resistor_SMD:R_0402_1005Metric_Pad0.72x0.64mm_HandSolder | C25744
R_2.2K | R10 | Resistor_SMD:R_0402_1005Metric_Pad0.72x0.64mm_HandSolder | C4190
R_1K | R12,R13,R14,R15,R37,R38,R39,R40,R45,R46,R47,R48 | Resistor_SMD:R_0603_1608Metric_Pad0.98x0.95mm_HandSolder | C21190
R_10K_0402 | R16,R17,R18,R19,R41,R42,R43,R44,R49,R50,R51,R52,R53,R54,R55,R56 | Resistor_SMD:R_0402_1005Metric_Pad0.72x0.64mm_HandSolder | C25744
22.1K | R25 | Resistor_SMD:R_0402_1005Metric_Pad0.72x0.64mm_HandSolder | C2929993
47.5K | R26 | Resistor_SMD:R_0603_1608Metric_Pad0.98x0.95mm_HandSolder | C23061
1K | R27,R69,R70,R71,R72,R73 | Resistor_SMD:R_0402_1005Metric_Pad0.72x0.64mm_HandSolder | C11702
R_100 | R31,R59,R63 | Resistor_SMD:R_0402_1005Metric_Pad0.72x0.64mm_HandSolder | C25076
R_1K_0402 | R57,R58,R60,R61,R62,R64,R65,R66 | Resistor_SMD:R_0402_1005Metric_Pad0.72x0.64mm_HandSolder | C11702
100K | R6 | Resistor_SMD:R_0402_1005Metric_Pad0.72x0.64mm_HandSolder | C25741
13K | R7 | Resistor_SMD:R_0603_1608Metric | C22797
R_20K | R9 | Resistor_SMD:R_0402_1005Metric_Pad0.72x0.64mm_HandSolder | C25765
MCP23017_SS | U1 | Package_SO:SOIC-28W_7.5x17.9mm_P1.27mm | C47023
W5500 | U12 | Package_QFP:LQFP-48_7x7mm_P0.5mm | C32843
REG_AMS1117-3.3 | U3 | Package_TO_SOT_SMD:SOT-223-3_TabPin2 | C347222
MIC29302WU | U4 | Package_TO_SOT_SMD:TO-263-5_TabPin3 | C11149
TLP291-4 | U5,U9,U10 | Package_SO:SOP-16_4.4x10.4mm_P1.27mm | C60900
CP2102N-Axx-xQFN28 | U6 | Package_DFN_QFN:QFN-28-1EP_5x5mm_P0.5mm_EP3.35x3.35mm | C964632
ESP32-S3-WROOM-1 | U7 | Espressif:ESP32-S3-WROOM-1 | C2913199
REG_MT2492 | U8 | Package_TO_SOT_SMD:SOT-23-6_Handsoldering | C89358

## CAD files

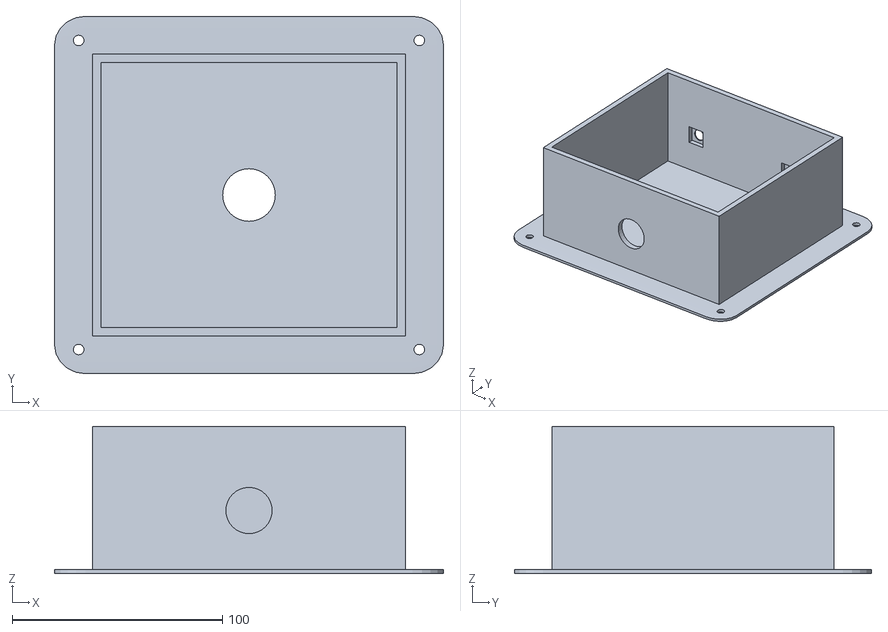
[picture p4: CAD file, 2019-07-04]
model/controller.stl
185.0 x 170.0 x 70.0

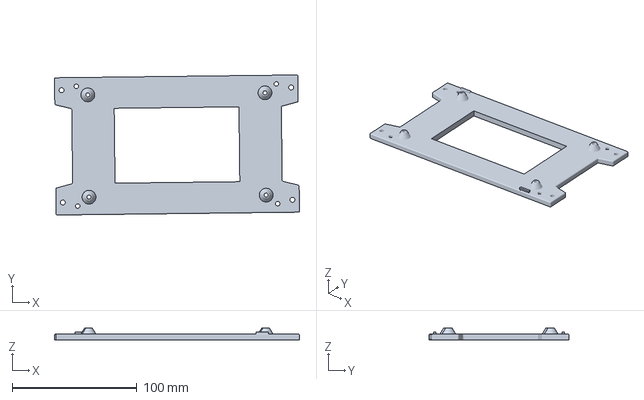
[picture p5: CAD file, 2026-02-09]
model/controller/controller-plate.3mf
196.4 x 112.3 x 10.0 mm

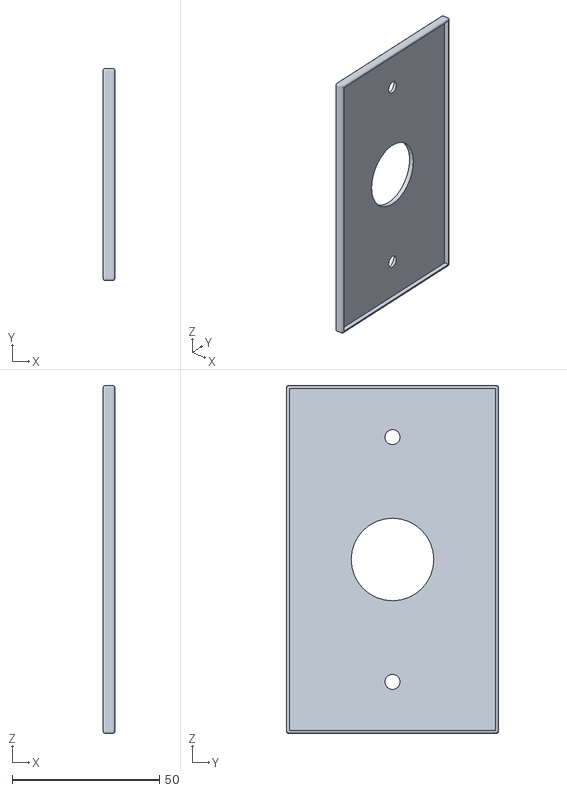
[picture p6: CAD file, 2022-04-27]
model/residential/residential.stl
4.00 x 72.0 x 118.0

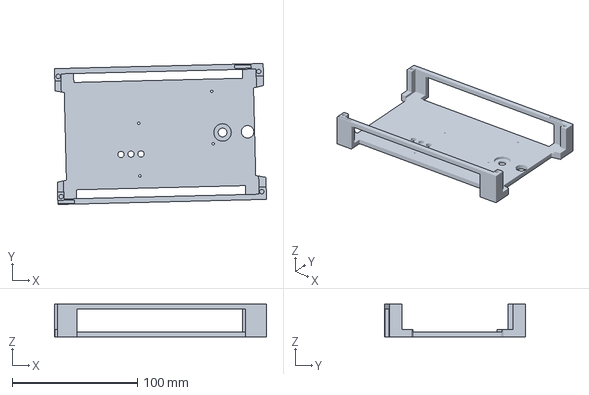
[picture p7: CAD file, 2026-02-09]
model/controller/controller-cover.3mf
169.4 x 112.7 x 26.0 mm

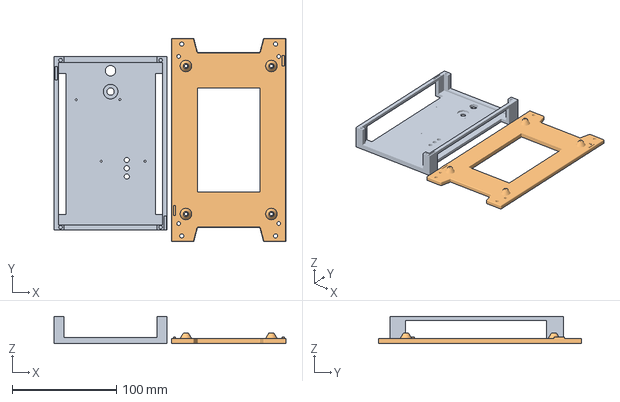
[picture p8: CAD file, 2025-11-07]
model/controller/controller.3mf
222.6 x 195.1 x 26.0 mm
controller-cover.stl
controller-plate.stl

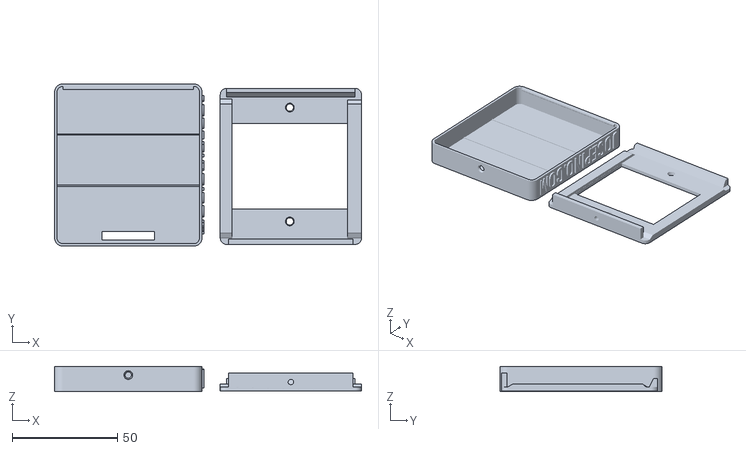
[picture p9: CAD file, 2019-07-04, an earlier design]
model/old/Arduino_3x4___4x4_Keypad_Case/files/Keypad_4x4_case.stl
145.6 x 77.0 x 11.9

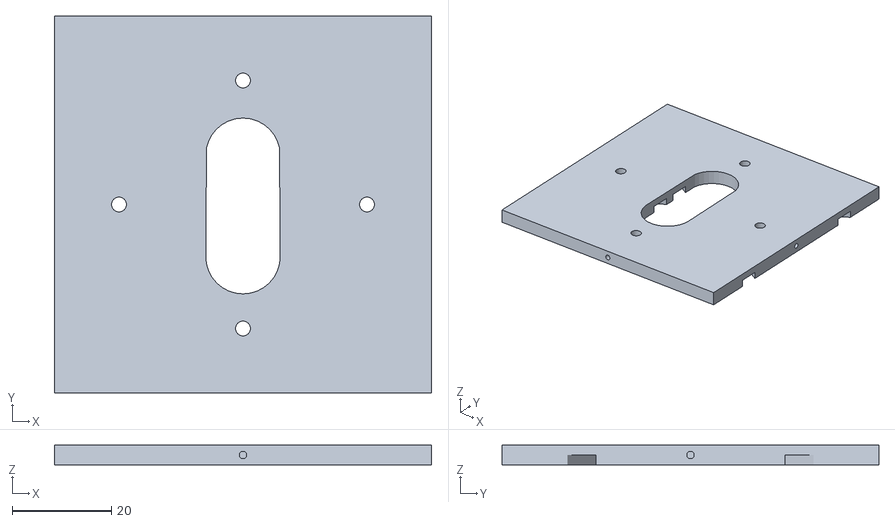
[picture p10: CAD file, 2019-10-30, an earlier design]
model/old/wallplate.stl
76.0 x 76.0 x 4.00

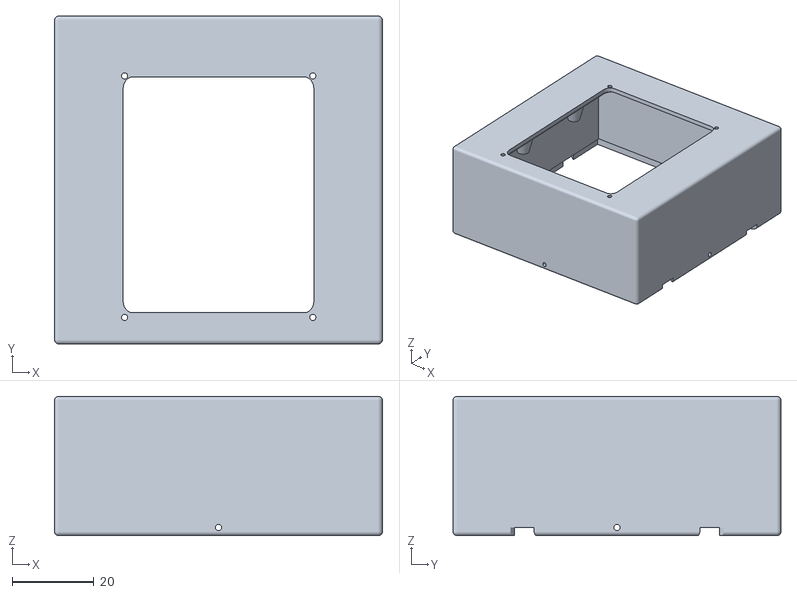
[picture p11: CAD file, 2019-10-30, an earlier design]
model/old/keypad.stl
80.0 x 80.0 x 34.0

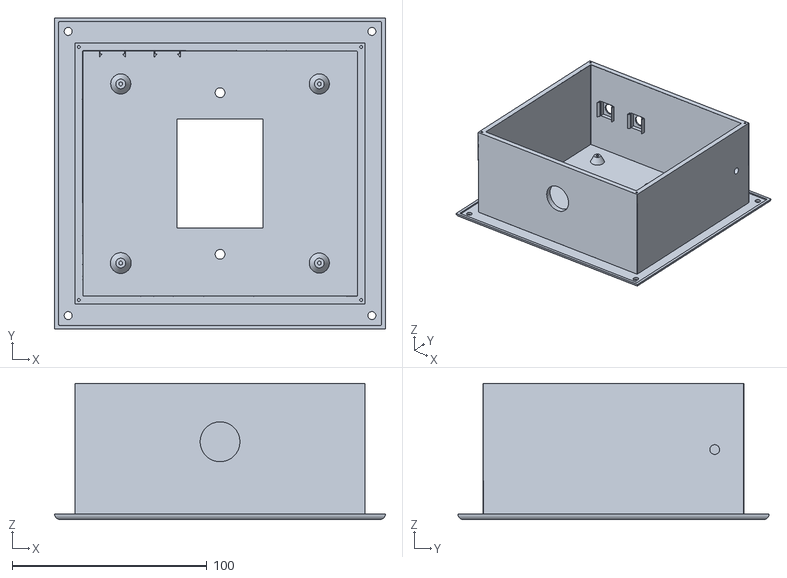
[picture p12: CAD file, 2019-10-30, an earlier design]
model/old/box.stl
170.0 x 160.0 x 70.0

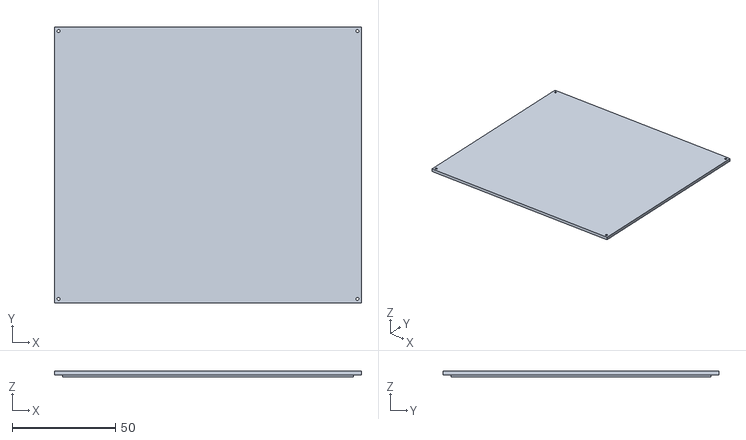
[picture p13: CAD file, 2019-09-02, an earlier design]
model/old/lid.stl
149.0 x 134.0 x 3.00

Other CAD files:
model/controller/controller-cover.stl
model/controller/controller-plate.stl
model/controller/controller.blend
model/controller/controller.stl
model/old/box.blend
model/old/keypad.blend
model/old/nfc.blend
model/residential/residential.blend

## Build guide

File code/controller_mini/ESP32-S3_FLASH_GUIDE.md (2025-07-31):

# ESP32-S3 Flash Issues with ESP-IDF 6.0 - Complete Guide

## The Problem
ESP-IDF 6.0 introduced changes that break auto-reset functionality on many ESP32-S3 boards. This means the automatic bootloader mode detection no longer works reliably.

**Error you see**: `Wrong boot mode detected (0x2a)! The chip needs to be in download mode.`

## Root Cause
- ESP-IDF 6.0 changed reset timing and sequences
- ESP32-S3 auto-reset circuits are more sensitive than ESP32 classic
- Some boards lack proper auto-reset circuitry entirely

## 🛠️ SOLUTIONS (Try in Order)

### Solution 1: Manual Reset Method (Most Reliable)

1. **Put ESP32-S3 in Download Mode MANUALLY:**
   ```bash
   # On your ESP32-S3 board:
   # 1. HOLD DOWN the BOOT button (and keep holding)
   # 2. While holding BOOT, press and release the RESET button  
   # 3. RELEASE the BOOT button
   # 4. Board is now in download mode (usually LED changes or goes off)
   ```

2. **Flash with no_reset (already configured):**
   ```bash
   idf.py -p /dev/ttyUSB0 flash
   ```

### Solution 2: Direct esptool with Custom Timing
```bash
python -m esptool --chip esp32s3 -p /dev/ttyUSB0 -b 115200 \
    --before no_reset_no_sync --after hard_reset \
    --connect-attempts 1 \
    write_flash --flash_mode dio --flash_freq 80m --flash_size 16MB \
    0x0 build/bootloader/bootloader.bin \
    0x10000 build/controller.bin \
    0x8000 build/partition_table/partition-table.bin \
    0xe000 build/ota_data_initial.bin
```

### Solution 3: Enhanced Development Script (Recommended)
```bash
# Auto-detect port and show all options
./flash_esp32s3.sh

# Or specify port manually
./flash_esp32s3.sh /dev/ttyUSB0
```

**Features:**
- 🔍 **Auto-detects** USB ports (supports multiple devices)
- 🔨 **Build** option - compile project only
- 🔥 **Flash** options - multiple flash methods with manual reset guidance
- 📊 **Monitor** option - view serial output
- 🔄 **Full cycle** - build → flash → monitor in one command
- ⚡ **Smart workflow** - handles build failures and provides clear feedback

### Solution 4: Alternative Reset Configuration

If manual reset doesn't work, try changing back to default_reset with slower baud:

```bash
# Edit sdkconfig:
CONFIG_ESPTOOLPY_BEFORE="default_reset"
CONFIG_ESPTOOLPY_BEFORE_RESET=y
CONFIG_ESPTOOLPY_BAUD_115200B=y
CONFIG_ESPTOOLPY_BAUD="115200"

# Then rebuild and flash:
idf.py build
idf.py -p /dev/ttyUSB0 flash
```

## 🔍 Troubleshooting

### If Manual Reset Still Fails:
1. **Check connections**: Ensure USB cable is data-capable (not charge-only)
2. **Try different USB port**: Some ports have power/timing differences  
3. **Check board variant**: Some ESP32-S3 boards have different BOOT/RESET button layouts
4. **Verify download mode**: LED should change state when in download mode

### Board-Specific Notes:
- **ESP32-S3-DevKitC**: Hold BOOT (IO0), press RESET (EN), release BOOT
- **ESP32-S3-WROOM**: Some variants need longer BOOT hold time (3+ seconds)
- **Custom boards**: May not have auto-reset circuitry at all

### Success Indicators:
```
esptool.py v4.9.0
Serial port /dev/ttyUSB0
Connecting....
Chip is ESP32-S3 (revision v0.2)
```

### Still Having Issues?
1. Use a different ESP32-S3 board to verify
2. Try ESP-IDF 5.3 for comparison  
3. Check board documentation for specific reset procedure
4. Consider using JTAG instead of UART for programming

## 📋 Current Configuration
The controller has been configured with:
- `CONFIG_ESPTOOLPY_BEFORE="no_reset"` - Requires manual reset
- `CONFIG_HTTPD_WS_SUPPORT=y` - WebSocket support enabled
- `CONFIG_PARTITION_TABLE_CUSTOM=y` - Using custom 2M partition table
- `CONFIG_ESPTOOLPY_FLASHSIZE="16MB"` - 16MB flash size

This configuration builds successfully and is ready for manual flash.

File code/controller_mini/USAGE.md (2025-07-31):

# ESP32-S3 Access Controller - Quick Usage Guide

## 🚀 Enhanced Development Workflow

### One-Command Development
```bash
# Run the enhanced script - it auto-detects everything!
./flash_esp32s3.sh
```

### Available Options:
1. **Build only** - Compile project without flashing
2. **Build and Flash** - Full build → flash cycle  
3. **Flash only** - Flash pre-built binary (requires build first)
4. **Monitor only** - View serial output from device
5. **Flash and Monitor** - Flash then immediately monitor
6. **Full cycle** - Build → Flash → Monitor (complete development cycle)
7. **Show manual commands** - Display raw commands for manual use

### Port Detection
- **Auto-detects** USB ports (`/dev/ttyUSB*`, `/dev/ttyACM*`)
- **Single device**: Automatically selects the port
- **Multiple devices**: Prompts you to choose
- **Manual override**: `./flash_esp32s3.sh /dev/ttyUSB1`

### ESP32-S3 Manual Reset (Required for ESP-IDF 6.0)
When flashing, you'll need to manually put ESP32-S3 in download mode:

1. **HOLD** the BOOT button (keep holding)
2. **PRESS and RELEASE** the RESET button  
3. **RELEASE** the BOOT button
4. Board LED should change (indicates download mode)
5. Press ENTER to start flashing

## 🛠️ Manual Commands

### Individual Commands
```bash
# Build
idf.py build

# Flash (after manual reset)
idf.py -p /dev/ttyUSB0 flash

# Monitor
idf.py -p /dev/ttyUSB0 monitor

# All-in-one
idf.py -p /dev/ttyUSB0 flash monitor
```

### Direct esptool (if needed)
```bash
python -m esptool --chip esp32s3 -p /dev/ttyUSB0 -b 115200 \
    --before no_reset_no_sync --after hard_reset \
    write_flash --flash_mode dio --flash_freq 80m --flash_size 16MB \
    0x0 build/bootloader/bootloader.bin \
    0x10000 build/controller.bin \
    0x8000 build/partition_table/partition-table.bin \
    0xe000 build/ota_data_initial.bin
```

## ⚡ Quick Workflow

### Development Cycle
1. Make code changes
2. Run `./flash_esp32s3.sh`
3. Choose option **6** (Full cycle)
4. Follow manual reset instructions when prompted
5. View output in monitor

### Just Testing
1. Run `./flash_esp32s3.sh`  
2. Choose option **4** (Monitor only)
3. See live output from your device

## 🔧 Troubleshooting

### If Script Fails
- Check USB connection
- Try different USB port  
- Verify ESP32-S3 is in download mode
- See `ESP32-S3_FLASH_GUIDE.md` for detailed troubleshooting

### Build Issues
- Run `idf.py build` first to see detailed error messages
- All ESP-IDF 6.0 compatibility issues have been resolved

### Monitor Issues  
- Press device RESET button if no output appears
- Verify correct baud rate (default: 115200)
- Use Ctrl+] to exit monitor

## 📁 Files Overview
- `flash_esp32s3.sh` - Enhanced development script
- `ESP32-S3_FLASH_GUIDE.md` - Detailed troubleshooting guide  
- `USAGE.md` - This quick reference
- `sdkconfig` - ESP-IDF 6.0 compatible configuration

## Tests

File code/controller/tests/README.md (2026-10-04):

# Access Controller Test Suite

Comprehensive automated test suite for the ESP32-S3 Access Controller. Covers API endpoints, configuration toggles, bulk user operations, Playwright browser tests, and interactive physical hardware verification.

## Quick Start

```bash
cd code/controller/tests
npm install
npx playwright install chromium
```

## Offline verification

These commands do not contact a device:

| Command | Checks |
|---|---|
| `npm run test:wiegand-format` | Native Wiegand format handling |
| `npm run test:boot-audio` | Startup sampling, timers and quiet mode |
| `npm run test:ui-network` | Desktop/mobile navigation, IP badges and simulated reboot recovery |

Set `CHROMIUM_PATH=/usr/bin/google-chrome` to use installed Chrome.
UI screenshots go to `artifacts/network-ui/` or `$ARTIFACT_DIR`.

## Attached-device usage

The commands below contact a controller and may change lock/input settings.

```bash
npm test              # Full automated suite (API + stress + UI)
npm run test:api      # API state & config only
npm run test:quick    # Smoke test (state + connectivity)
npm run test:ui       # Playwright browser tests only
npm run test:physical # Interactive hardware walkthrough
```

Or with environment variables:
```bash
DEVICE_URL=http://192.168.1.131 npm test
```

## Test Suites

| Suite | File | Tests | Description |
|---|---|---|---|
| **Build Verification** | `runner.mjs` | 5 | Firmware binaries exist |
| **API State & Monitoring** | `suites/api-state.mjs` | 19 | GET endpoints: state, logs, wiegand, rf, wifi, caching |
| **API Configuration** | `suites/api-config.mjs` | 29 | POST endpoints: lock, exit, fob, keypad toggles + PIN user CRUD + channel isolation |
| **Stress & Bulk** | `suites/stress-bulk.mjs` | 39 | 30-user bulk CRUD, comprehensive toggle sweep with log verification, Wiegand/RF registration flows |
| **Web UI (Playwright)** | `suites/ui-playwright.mjs` | 32 | Every checkbox on both channels, PIN user CRUD, tab navigation, WiFi/Server forms |
| **Physical Hardware** | `suites/physical-hardware.mjs` | 11 | Interactive: exit buttons, contacts, keypads, fobs, RFID scan, motion, buzzer |

## Device Auto-Detection

The runner automatically finds the device:
1. Checks `DEVICE_URL` environment variable
2. Tries `http://192.168.4.1` (AP mode default)
3. Any other reachable IP

Connect to the device's WiFi AP (`ac_xxxx`, password `pyfitech`) or set `DEVICE_URL`.

## Log Verification

The stress-bulk suite verifies that every arm/disarm action produces a corresponding log entry on the controller with the correct source tag (`[api]`, `[exit_auto]`, `[fob_auto]`, etc.).

## Report

After each run, `test-report.html` is generated with:
- Summary cards (total, passed, failed)
- Per-suite tables with test names, results, durations
- System information (UUID, channel counts, user counts)

## Physical Hardware Tests

Requires hardware connected. Each test:
1. Prints a large banner with instructions
2. Waits for you to press Enter (or type `skip`)
3. Verifies state/logs changed

```bash
npm run test:physical
```

## Files

```
tests/
├── runner.mjs              # Main entry point
├── package.json            # npm config
├── lib/
│   ├── api-client.mjs      # Full API client (28 endpoints)
│   ├── config.mjs          # Device URL, timeouts
│   └── report.mjs          # HTML report generator
├── suites/
│   ├── api-state.mjs       # GET state/monitoring tests
│   ├── api-config.mjs      # POST config toggle tests
│   ├── stress-bulk.mjs     # Bulk CRUD + toggle sweep
│   ├── ui-playwright.mjs   # Browser UI tests
│   └── physical-hardware.mjs # Interactive hardware tests
└── test-report.html        # Generated report
```

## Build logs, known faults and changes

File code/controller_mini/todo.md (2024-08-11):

wifi on disconnect with periodic check for known AP
add RFID user, where did pin user go?
full system test

add toggles from local page to card details component
add enable/disable user based on schedule'd event from automator
add automator event for schedule via button: remove/modify/schedule
add groups so you can just apply settings from/to group

make sure there are no memory leaks in local page
fix mem. leak with message queues are full

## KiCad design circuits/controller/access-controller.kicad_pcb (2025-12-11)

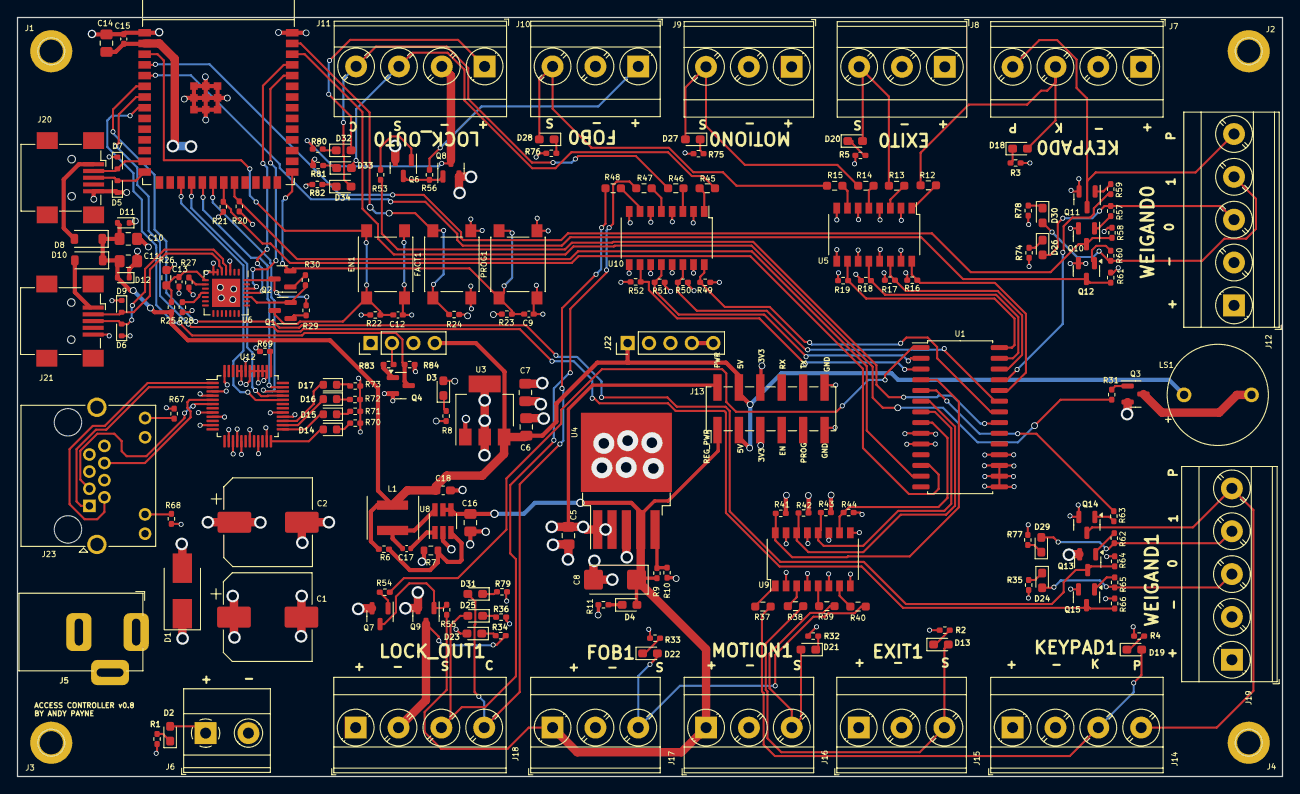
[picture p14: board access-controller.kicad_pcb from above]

Board: 4 copper layers, 150.0 x 90.0 mm, 186 parts (0 on the bottom side), 138 nets.

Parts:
C1, C2: C_470uF; CP_Elec_10x10
C5, C6, C7, C10, C11, C14, C16: C_10uF; C_0805_2012Metric_Pad1.18x1.45mm_HandSolder
C8: C_10uF_Ta; CP_EIA-6032-15_Kemet-U_Pad2.25x2.35mm_HandSolder
C9, C12, C13: 1uF; C_0402_1005Metric_Pad0.74x0.62mm_HandSolder
C15: 100nF; C_0402_1005Metric_Pad0.74x0.62mm_HandSolder
C17: 22nF; C_0402_1005Metric
C18: C_22uF; C_0603_1608Metric_Pad1.08x0.95mm_HandSolder
D1: D_Zener; D_SMB_Handsoldering
D2, D3, D4, D13, D18, D19, D20, D21, D22, D23, D24, D25, D26, D27, D28, D29, D30, D31, D32, D33, D34: White; LED_0603_1608Metric_Pad1.05x0.95mm_HandSolder
D5, D6, D7, D9, D11, D12: ESD_5V; D_SOD-523
D8, D10: D_1N5819HW; D_SOD-123
D14, D15, D16, D17: Red; LED_0603_1608Metric
EN1: SW_PUSH; SW_SPST_PTS645
FACT1: SW_PUSH; SW_SPST_PTS645
J1, J2, J3, J4: Conn_01x01_Female; Mount_Hole
J5: Barrel_Jack_Switch; BarrelJack_OD5.5_ID2.5
J6: Screw_Terminal_01x02; TerminalBlock_Phoenix_MKDS-1,5-2-5.08_1x02_P5.08mm_Horizont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
J7, J11, J14, J18: Terminal_01x04; TerminalBlock_Phoenix_MKDS-3-4-5.08_1x04_P5.08mm_Horizontal
J8, J9, J10, J15, J16, J17: Terminal_01x03; TerminalBlock_Phoenix_MKDS-3-3-5.08_1x03_P5.08mm_Horizontal
J12, J19: Screw_Terminal_01x05; TerminalBlock_Phoenix_MKDS-3-5-5.08_1x05_P5.08mm_Horizontal
J13: Conn_02x06_Odd_Even; PinHeader_2x06_P2.54mm_Vertical_SMD
J20, J21: USB_MINI_B; USB_Mini-B_Wuerth_65100516121_Horizontal
J22: RF_MODULE; RXB6_RF_MODULE
J23: CONN_RJ45; RJ45_Amphenol_RJHSE538X
L1: 10uH; L_4x4
LS1: TMB12A05; S_YXDZ
PROG1: SW_PUSH; SW_SPST_PTS645
Q1: Q_L8050QLT1G; SOT-23
Q2: Q_L8550HQLT1G; SOT-23
Q3, Q4, Q6, Q7, Q10, Q11, Q12, Q13, Q14, Q15: Q_MMBT5551; SOT-23
Q8, Q9: Q_AO3400A; SOT-23
R1, R2, R3, R4, R5, R8, R11, R20, R21, R22, R23, R24, R28, R29, R30, R32, R33, R34, R35, R36, R67, R68, R74, R75, R76, R77, R78, R79, R80, R81, R82, R83, R84: 10K; R_0402_1005Metric_Pad0.72x0.64mm_HandSolder
R6: 100K; R_0402_1005Metric_Pad0.72x0.64mm_HandSolder
R7: 13K; R_0603_1608Metric
R9: R_20K; R_0402_1005Metric_Pad0.72x0.64mm_HandSolder
R10: R_2.2K; R_0402_1005Metric_Pad0.72x0.64mm_HandSolder
R12, R13, R14, R15, R37, R38, R39, R40, R45, R46, R47, R48: R_1K; R_0603_1608Metric_Pad0.98x0.95mm_HandSolder
R16, R17, R18, R19, R41, R42, R43, R44, R49, R50, R51, R52, R53, R54, R55, R56: R_10K_0402; R_0402_1005Metric_Pad0.72x0.64mm_HandSolder
R25: 22.1K; R_0402_1005Metric_Pad0.72x0.64mm_HandSolder
R26: 47.5K; R_0603_1608Metric_Pad0.98x0.95mm_HandSolder
R27, R69, R70, R71, R72, R73: 1K; R_0402_1005Metric_Pad0.72x0.64mm_HandSolder
R31, R59, R63: R_100; R_0402_1005Metric_Pad0.72x0.64mm_HandSolder
R57, R58, R60, R61, R62, R64, R65, R66: R_1K_0402; R_0402_1005Metric_Pad0.72x0.64mm_HandSolder
U1: MCP23017_SS; SOIC-28W_7.5x17.9mm_P1.27mm
U3: REG_AMS1117-3.3; SOT-223-3_TabPin2
U4: MIC29302WU; TO-263-5_TabPin3
U5, U9, U10: TLP291-4; SOP-16_4.4x10.4mm_P1.27mm
U6: CP2102N-Axx-xQFN28; QFN-28-1EP_5x5mm_P0.5mm_EP3.35x3.35mm
U7: ESP32-S3-WROOM-1
U8: REG_MT2492; SOT-23-6_Handsoldering
U12: W5500; LQFP-48_7x7mm_P0.5mm

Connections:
/3V3: C7.1, C14.1, C15.1, D3.2 (A), J13.5, J13.6, R16.1, R17.1, R18.1, R19.1, R20.1, R21.2, R22.1, R23.1, R24.1, R27.1, R41.1, R42.1, R43.1, R44.1, R49.1, R50.1, R51.1, R52.1, R58.2, R61.2, R64.2, R66.2, R67.2, R69.2, R84.1, U1.9 (VDD), U1.18 (~RESET), U3.2 (Vout), U6.6 (VDD), U6.7 (VREGIN), U7.2 (3V3), U12.4 (AVDD), U12.8 (AVDD), U12.11 (AVDD), U12.15 (AVDD), U12.17 (AVDD), U12.21 (AVDD), U12.28 (VDD), U12.43 (PMODE2)
/5V: C6.1, C10.1, C11.1, C18.1, D8.1 (K), D10.1 (K), D11.2 (A2), D12.2 (A2), J13.3, J13.4, J22.4, J22.5, L1.2, LS1.1, R6.1, R25.2, U3.3 (Vin)
/ANTENNA: J22.8, J22.9
/BUZZER: R31.1, U7.38 (GPIO2/TOUCH2/ADC1_CH1)
/CS: U7.17 (GPIO9/TOUCH9/ADC1_CH8/FSPIHD/SUBSPIHD), U12.32 (~SCS)
/DATA: J22.2, R83.2
/DATA_IO: Q4.3 (C), R84.2, U7.8 (GPIO15/U0RTS/ADC2_CH4/XTAL_32K_P)
/EXIT0: D20.2 (A), J8.3, R13.2
/EXIT0_SENSE: R17.2, U1.26 (GPA5), U5.14
/EXIT1: D13.2 (A), J15.3, R38.2
/EXIT1_SENSE: R42.2, U1.6 (GPB5), U9.14
/Ethernet/RX_N: J23.6, U12.5 (RXN)
/Ethernet/RX_P: J23.3, U12.6 (RXP)
/Ethernet/TX_N: J23.2, U12.1 (TXN)
/Ethernet/TX_P: J23.1, U12.2 (TXP)
/FOB0: D28.2 (A), J10.3, R15.2
/FOB0_SENSE: R19.2, U1.28 (GPA7), U5.10
/FOB1: D22.2 (A), J17.3, R40.2
/FOB1_SENSE: R44.2, U1.8 (GPB7), U9.10
/KEYPAD0: D18.2 (A), J7.3, R12.2
/KEYPAD0_SENSE: R16.2, U1.24 (GPA3), U5.16
/KEYPAD1: D19.2 (A), J14.3, R37.2
/KEYPAD1_SENSE: R41.2, U1.4 (GPB3), U9.16
/LOCK0_CLOSE: D34.2 (A), J11.4, R46.2
/LOCK0_CLOSE_IO: R50.2, U1.23 (GPA2), U10.14
/LOCK0_CONTROL: R53.2, U1.21 (GPA0)
/LOCK0_OUT: J11.2, Q8.3 (D), R80.1
/LOCK0_SENSE: R49.2, U1.22 (GPA1), U10.16
/LOCK0_STATE: D33.2 (A), J11.3, R45.2
/LOCK1_CLOSE: D31.2 (A), J18.4, R48.2
/LOCK1_CLOSE_IO: R52.2, U1.3 (GPB2), U10.10
/LOCK1_CONTROL: R54.2, U1.1 (GPB0)
/LOCK1_OUT: J18.2, Q9.3 (D), R34.1
/LOCK1_SENSE: R51.2, U1.2 (GPB1), U10.12
/LOCK1_STATE: D25.2 (A), J18.3, R47.2
/MISO: U7.20 (GPIO12/TOUCH12/ADC2_CH1/FSPICLK/FSPIIO6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), U12.34 (MISO)
/MOSI: U7.19 (GPIO11/TOUCH11/ADC2_CH0/FSPID/FSPIIO5/S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), U12.35 (MOSI)
/MOTION0: D27.2 (A), J9.3, R14.2
/MOTION0_SENSE: R18.2, U1.27 (GPA6), U5.12
/MOTION1: D21.2 (A), J16.3, R39.2
/MOTION1_SENSE: R43.2, U1.7 (GPB6), U9.12
/Microcontroller/D+: D6.2 (A2), J21.3 (D+), U6.4 (D+)
/Microcontroller/D-: D9.2 (A2), J21.2 (D-), U6.5 (D-)
/Microcontroller/DTR: Q2.3 (C), R29.1, U6.28 (~DTR)
/Microcontroller/EN: C12.1, EN1.1, Q1.3 (C), R22.2, U7.3 (EN)
/Microcontroller/FACT: FACT1.1, R24.2, U7.39 (GPIO1/TOUCH1/ADC1_CH0)
/Microcontroller/IO19: D7.2 (A2), J20.2 (D-), U7.13 (GPIO19/U1RTS/ADC2_CH8/CLK_OUT2/USB_D-)
/Microcontroller/IO20: D5.2 (A2), J20.3 (D+), U7.14 (GPIO20/U1CTS/ADC2_CH9/CLK_OUT1/USB_D+)
/Microcontroller/IO43: U6.25 (RXD), U7.37 (U0TXD/GPIO43/CLK_OUT1)
/Microcontroller/IO44: U6.26 (TXD), U7.36 (U0RXD/GPIO44/CLK_OUT2)
/Microcontroller/PROG: C9.1, PROG1.1, Q2.2 (E), R23.2, U7.27 (GPIO0/BOOT)
/Microcontroller/RTS: Q1.2 (E), R30.1, U6.24 (~RTS)
/POWER: C1.1, C2.1, C5.1, D1.1 (K), D2.2 (A), D23.2 (A), D32.2 (A), J5.1, J6.1, J11.1, J13.2, J18.1, J23.4, J23.5, R68.2, U4.1 (EN), U4.2 (IN)
/PUSH0: J7.4, J12.5, Q11.3 (C)
/PUSH0_IO: R59.1, U1.25 (GPA4)
/PUSH1: J14.4, J19.5, Q14.3 (C)
/PUSH1_IO: R63.1, U1.5 (GPB4)
/REG_POWER: C8.1, C16.1, D4.2 (A), J7.1, J8.1, J9.1, J10.1, J12.1, J13.1, J14.1, J15.1, J16.1, J17.1, J19.1, R9.1, R55.2, R56.2, U4.4 (Output), U8.4 (EN), U8.5 (VIN)
/SCL: R21.1, U1.12 (SCK), U7.21 (GPIO13/TOUCH13/ADC2_CH2/FSPIQ/FSPIIO7/S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)
/SCLK: U7.18 (GPIO10/TOUCH10/ADC1_CH9/FSPICS0/FSPIIO4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), U12.33 (SCLK)
/SDA: R20.2, U1.13 (SDA), U7.22 (GPIO14/TOUCH14/ADC2_CH3/FSPIWP/FSPIDQS/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)
/WG0_DATA0: D26.2 (A), J12.3, R57.2
/WG0_DATA1: D30.2 (A), J12.4, R60.2
/WG0_DATA_SENSE0: Q10.3 (C), R58.1, U7.4 (GPIO4/TOUCH4/ADC1_CH3)
/WG0_DATA_SENSE1: Q12.3 (C), R61.1, U7.5 (GPIO5/TOUCH5/ADC1_CH4)
/WG1_DATA0: D24.2 (A), J19.3, R65.2
/WG1_DATA1: D29.2 (A), J19.4, R62.2
/WG1_DATA_SENSE0: Q13.3 (C), R64.1, U7.6 (GPIO6/TOUCH6/ADC1_CH5)
/WG1_DATA_SENSE1: Q15.3 (C), R66.1, U7.7 (GPIO7/TOUCH7/ADC1_CH6)
GND: C1.2, C2.2, C5.2, C6.2, C7.2, C8.2, C9.2, C10.2, C11.2, C12.2, C13.2, C14.2, C15.2, C16.2, C18.2, D1.2 (A), D5.1 (A1), D6.1 (A1), D7.1 (A1), D9.1 (A1), D11.1 (A1), D12.1 (A1), EN1.2, FACT1.2, J1.1, J2.1, J3.1, J4.1, J5.2, J5.3, J6.2, J7.2, J8.2, J9.2, J10.2, J12.2, J13.11, J13.12, J14.2, J15.2, J16.2, J17.2, J19.2, J20.5 (GND), J21.5 (GND), J22.1, J22.6, J22.7, J23.7, J23.8, J23.9, J23.11, PROG1.2, Q3.2 (E), Q4.2 (E), Q6.2 (E), Q7.2 (E), Q8.2 (S), Q9.2 (S), Q10.2 (E), Q11.2 (E), Q12.2 (E), Q13.2 (E), Q14.2 (E), Q15.2 (E), R1.1, R2.1, R3.1, R4.1, R5.1, R7.2, R8.1, R10.2, R11.1, R26.1, R28.2, R32.1, R33.1, R35.1, R36.1, R70.2, R71.2, R72.2, R73.2, R74.1, R75.1, R76.1, R77.1, R78.1, R79.1, R81.1, R82.1, U1.10 (VSS), U1.15 (A0), U1.16 (A1), U1.17 (A2), U3.1 (GND), U4.3 (GND), U5.2, U5.4, U5.6, U5.8, U5.9, U5.11, U5.13, U5.15, U6.3 (GND), U6.29 (GND), U7.1 (GND), U7.40 (GND), U7.41 (GND), U8.2 (GND), U9.2, U9.4, U9.6, U9.8, U9.9, U9.11, U9.13, U9.15, U10.2, U10.4, U10.6, U10.8, U10.9, U10.11, U10.13, U10.15, U12.3 (AGND), U12.9 (AGND), U12.14 (AGND), U12.16 (AGND), U12.19 (AGND), U12.23 (RSVD), U12.29 (GND), U12.38 (RSVD), U12.39 (RSVD), U12.40 (RSVD), U12.41 (RSVD), U12.42 (RSVD), U12.44 (PMODE1), U12.45 (PMODE0), U12.48 (AGND)
unnamed: D2.1 (K), R1.2
unnamed: D3.1 (K), R8.2
unnamed: D4.1 (K), R11.2
unnamed: D8.2 (A), J20.1 (VBUS)
unnamed: D10.2 (A), J21.1 (VBUS)
unnamed: D13.1 (K), R2.2
unnamed: D14.2 (A), U12.24 (SPDLED)
unnamed: D14.1 (K), R70.1
unnamed: D15.2 (A), U12.25 (LINKLED)
unnamed: D15.1 (K), R71.1
unnamed: D16.2 (A), U12.26 (DUPLED)
unnamed: D16.1 (K), R72.1
unnamed: D17.2 (A), U12.27 (ACTLED)
unnamed: D17.1 (K), R73.1
unnamed: D18.1 (K), R3.2
unnamed: D19.1 (K), R4.2
unnamed: D20.1 (K), R5.2
unnamed: D21.1 (K), R32.2
unnamed: D22.1 (K), R33.2
unnamed: D23.1 (K), R34.2
unnamed: D24.1 (K), R35.2
unnamed: D25.1 (K), R36.2
unnamed: D26.1 (K), R74.2
unnamed: D27.1 (K), R75.2
unnamed: D28.1 (K), R76.2
unnamed: D29.1 (K), R77.2
unnamed: D30.1 (K), R78.2
unnamed: D31.1 (K), R79.2
unnamed: D32.1 (K), R80.2
unnamed: D33.1 (K), R81.2
unnamed: D34.1 (K), R82.2
unnamed: J23.10, R68.1
unnamed: J23.12, R67.1
unnamed: Q1.1 (B), R29.2
unnamed: Q2.1 (B), R30.2
unnamed: Q3.1 (B), R31.2
unnamed: LS1.2, Q3.3 (C)
unnamed: Q4.1 (B), R83.1
unnamed: Q6.1 (B), R53.1
unnamed: Q6.3 (C), Q8.1 (G), R56.1
unnamed: Q7.1 (B), R54.1
unnamed: Q7.3 (C), Q9.1 (G), R55.1
unnamed: Q10.1 (B), R57.1
unnamed: Q11.1 (B), R59.2
unnamed: Q12.1 (B), R60.1
unnamed: Q13.1 (B), R62.1
unnamed: Q14.1 (B), R63.2
unnamed: Q15.1 (B), R65.1
unnamed: R12.1, U5.1
unnamed: R13.1, U5.3
unnamed: R14.1, U5.5
unnamed: R15.1, U5.7
unnamed: R37.1, U9.1
unnamed: R38.1, U9.3
unnamed: R39.1, U9.5
unnamed: R40.1, U9.7
unnamed: R45.1, U10.1
unnamed: R46.1, U10.3
unnamed: R47.1, U10.5
unnamed: R48.1, U10.7
unnamed: R9.2, R10.1, U4.5 (Feedback)
unnamed: C13.1, R25.1, R26.2, U6.8 (VBUS)
unnamed: R27.2, U6.9 (~RST)
unnamed: R28.1, U6.11 (~SUSPEND)
unnamed: C17.1, U8.1 (BS)
unnamed: R6.2, R7.1, U8.3 (FB)
unnamed: C17.2, L1.1, U8.6 (SW)
unnamed: R69.1, U12.37 (~RST)

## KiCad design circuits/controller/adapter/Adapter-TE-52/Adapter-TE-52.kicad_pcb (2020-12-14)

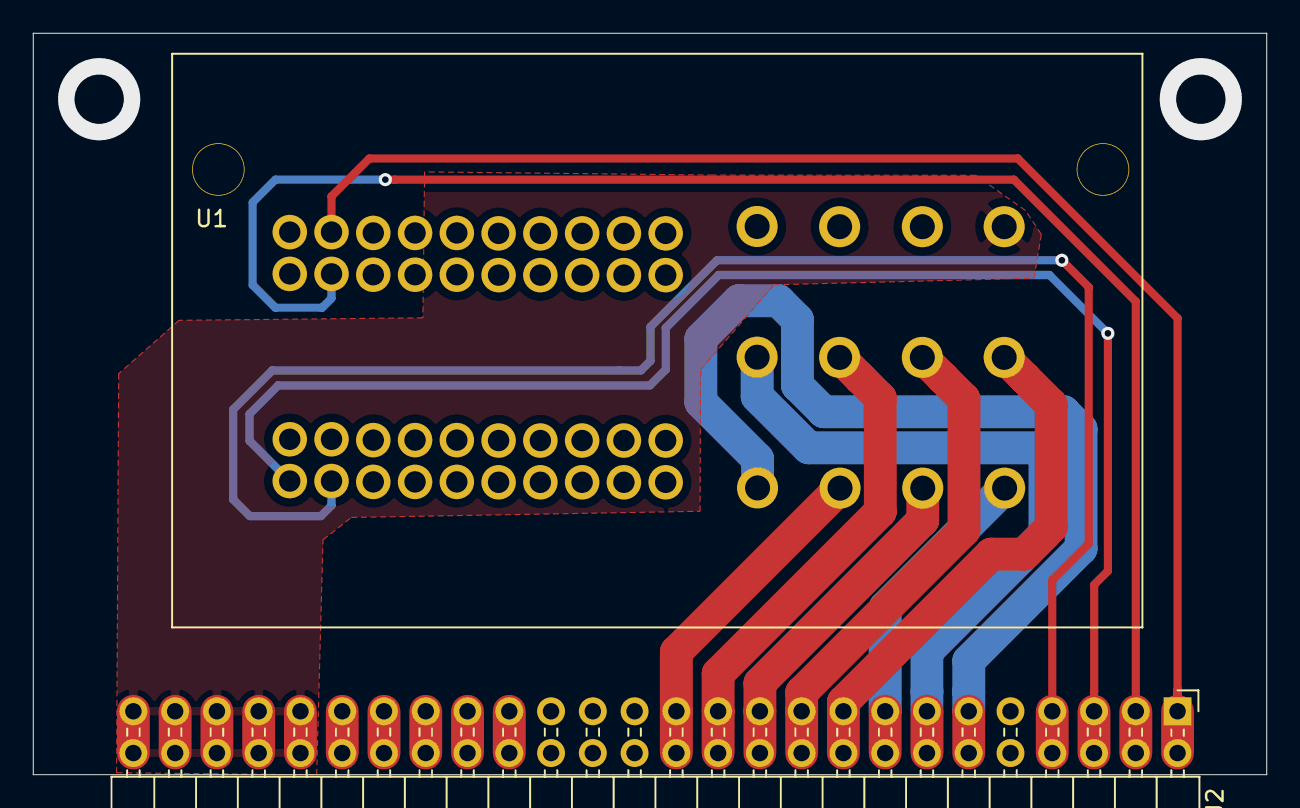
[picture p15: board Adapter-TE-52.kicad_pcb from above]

Board: 2 copper layers, 75.0 x 45.1 mm, 3 parts (1 on the bottom side), 14 nets.

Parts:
LOGO: LOGO
U1: Adapter-TE-52
U2: TE-AUTO-CONN-52

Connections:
/BATTERY: U1.44, U2.44
/CAMERA+: U1.31, U2.31
/CAMERA-: U1.32, U2.32
/CAN+: U1.2, U2.2
/CAN-: U1.12, U2.12
/LF+: U1.47, U2.47
/LF-: U1.51, U2.51
/LR+: U1.48, U2.48
/LR-: U1.52, U2.52
/RF+: U1.46, U2.46
/RF-: U1.50, U2.50
/RR+: U1.45, U2.45
/RR-: U1.49, U2.49
GND: U1.33, U1.43, U2.33, U2.43

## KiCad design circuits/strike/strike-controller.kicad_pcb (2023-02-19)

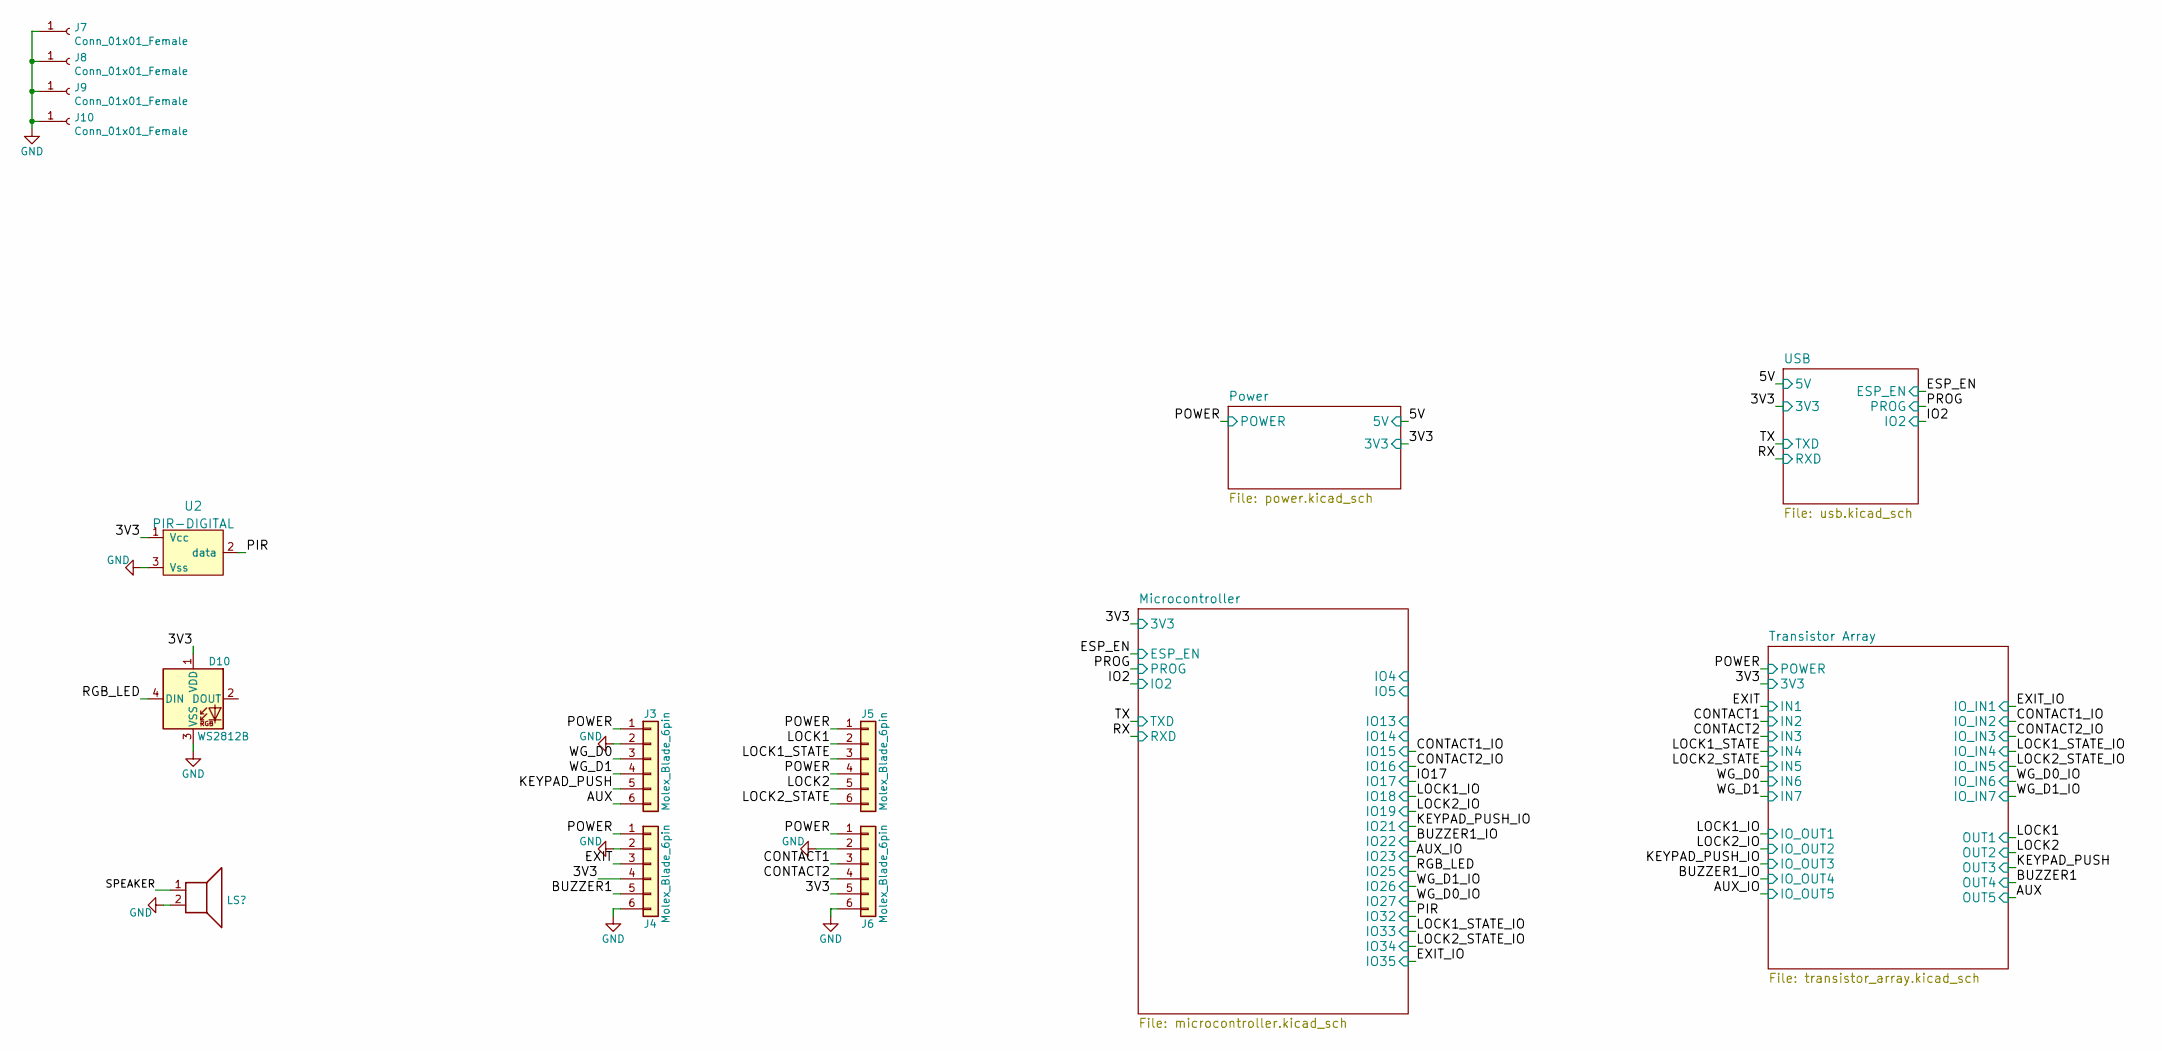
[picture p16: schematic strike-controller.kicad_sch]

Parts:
D10: WS2812B; LED_WS2812B_PLCC4_5.0x5.0mm_P3.2mm
J3, J4, J5, J6: Molex_Blade_6pin; Molex_PicoBlade_53261-0671_1x06-1MP_P1.25mm_Horizontal; Part Number 533980671; LCSC C395347
J7, J8, J9, J10: Conn_01x01_Female; Mount_Hole_1p5
U2: PIR-DIGITAL; TO-5-3; Part Number PYQ2898

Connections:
+3V3: D10.1 (VDD), J4.4, J6.5, U2.1 (Vcc); also elsewhere on the board
/AUX: J3.6; also elsewhere on the board
/BUZZER1: J4.5; also elsewhere on the board
/CONTACT1: J6.3; also elsewhere on the board
/CONTACT2: J6.4; also elsewhere on the board
/EXIT: J4.3; also elsewhere on the board
/KEYPAD_PUSH: J3.5; also elsewhere on the board
/LOCK1: J5.2; also elsewhere on the board
/LOCK1_STATE: J5.3; also elsewhere on the board
/LOCK2: J5.5; also elsewhere on the board
/LOCK2_STATE: J5.6; also elsewhere on the board
/PIR: U2.2 (data); also elsewhere on the board
/POWER: J3.1, J4.1, J5.1, J5.4, J6.1; also elsewhere on the board
/RGB_LED: D10.4 (DIN); also elsewhere on the board
/WG_D0: J3.3; also elsewhere on the board
/WG_D1: J3.4; also elsewhere on the board
GND: D10.3 (VSS), J3.2, J4.2, J4.6, J6.2, J6.6, J7.1, J8.1, J9.1, J10.1, U2.3 (Vss); also elsewhere on the board

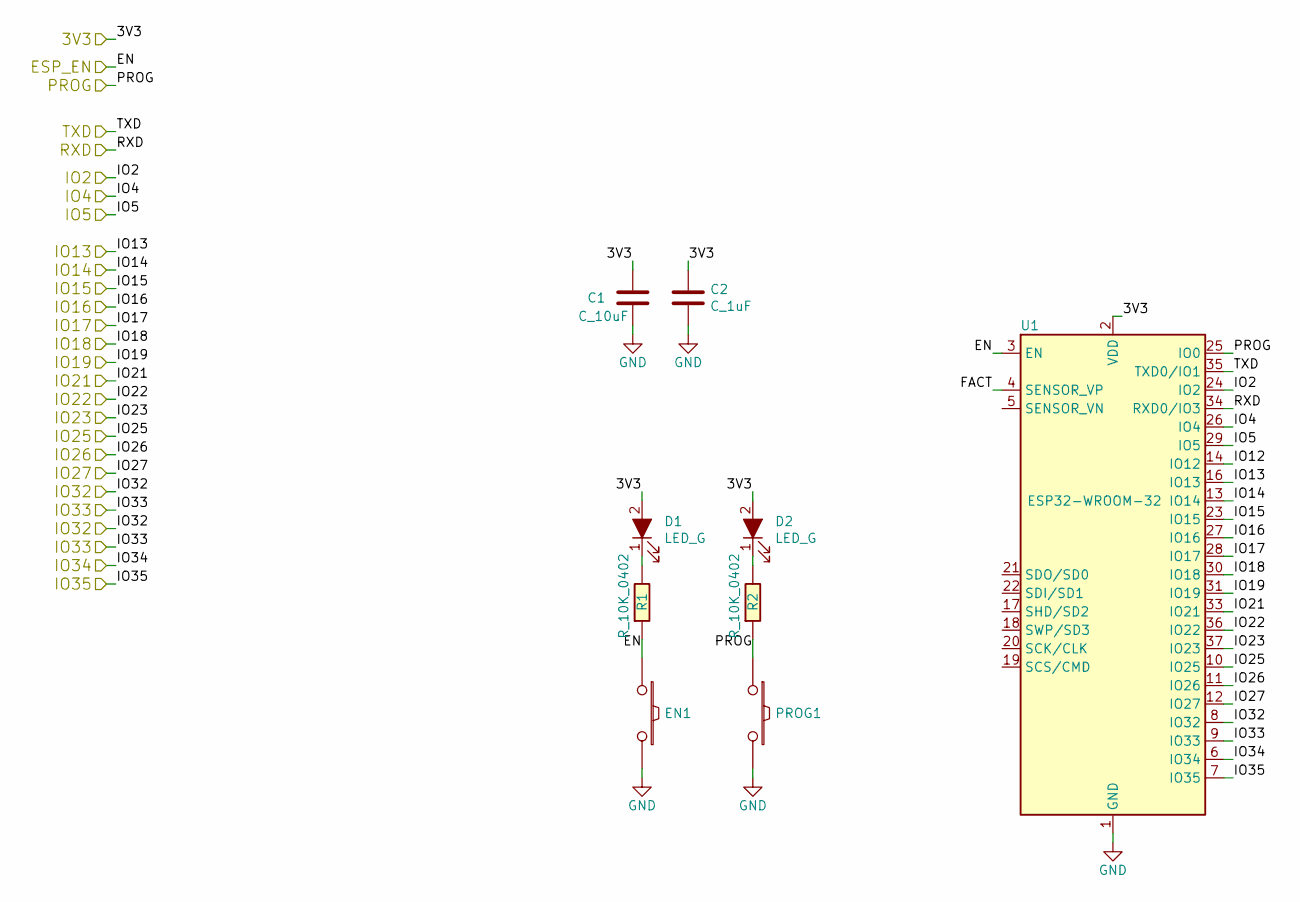
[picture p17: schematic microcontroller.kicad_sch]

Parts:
C1: C_10uF; C_0603_1608Metric_Pad1.08x0.95mm_HandSolder; Part Number CL10A106MA8NRNC; LCSC C96446
C2: C_1uF; C_0402_1005Metric_Pad0.74x0.62mm_HandSolder; Part Number CL05A105KA5NQNC; LCSC C52923
D1, D2: LED_G; D_0603_1608Metric_Pad1.05x0.95mm_HandSolder; Part Number 19-217/BHC-ZL1M2RY/3T; LCSC C72041
EN1: SW_PUSH_SM; SW_SPST_TL3342; Part Number TS-1187A-B-A-B; LCSC C318884
PROG1: SW_PUSH_SM; SW_SPST_TL3342; Part Number TS-1187A-B-A-B; LCSC C318884
R1, R2: R_10K_0402; R_0402_1005Metric_Pad0.72x0.64mm_HandSolder; Part Number 0402WGF1002TCE; LCSC C25744
U1: ESP32-WROOM-32; LCSC C82899

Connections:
+3V3: C1.1, C2.1, D1.2 (A), D2.2 (A), U1.2 (VDD); also elsewhere on the board
/AUX_IO: U1.37 (IO23); also elsewhere on the board
/BUZZER1_IO: U1.36 (IO22); also elsewhere on the board
/CONTACT1_IO: U1.23 (IO15); also elsewhere on the board
/CONTACT2_IO: U1.27 (IO16); also elsewhere on the board
/ESP_EN: EN1.1, R1.1, U1.3 (EN); also elsewhere on the board
/EXIT_IO: U1.13 (IO14); also elsewhere on the board
/IO2: U1.24 (IO2); also elsewhere on the board
/IO17: U1.28 (IO17)
/KEYPAD_PUSH_IO: U1.33 (IO21); also elsewhere on the board
/LOCK1_IO: U1.30 (IO18); also elsewhere on the board
/LOCK1_STATE_IO: U1.9 (IO33); also elsewhere on the board
/LOCK2_IO: U1.31 (IO19); also elsewhere on the board
/LOCK2_STATE_IO: U1.6 (IO34); also elsewhere on the board
/Microcontroller/FACT: U1.4 (SENSOR_VP)
/Microcontroller/IO4: U1.26 (IO4)
/Microcontroller/IO5: U1.29 (IO5)
/Microcontroller/IO12: U1.14 (IO12)
/Microcontroller/IO13: U1.16 (IO13)
/Microcontroller/IO35: U1.7 (IO35)
/PIR: U1.8 (IO32); also elsewhere on the board
/PROG: PROG1.1, R2.1, U1.25 (IO0); also elsewhere on the board
/RGB_LED: U1.10 (IO25); also elsewhere on the board
/RX: U1.34 (RXD0/IO3); also elsewhere on the board
/TX: U1.35 (TXD0/IO1); also elsewhere on the board
/WG_D0_IO: U1.12 (IO27); also elsewhere on the board
/WG_D1_IO: U1.11 (IO26); also elsewhere on the board
GND: C1.2, C2.2, EN1.2, PROG1.2, U1.1 (GND), U1.15 (GND), U1.38 (GND), U1.39 (GND); also elsewhere on the board
unnamed: D1.1 (K), R1.2
unnamed: D2.1 (K), R2.2

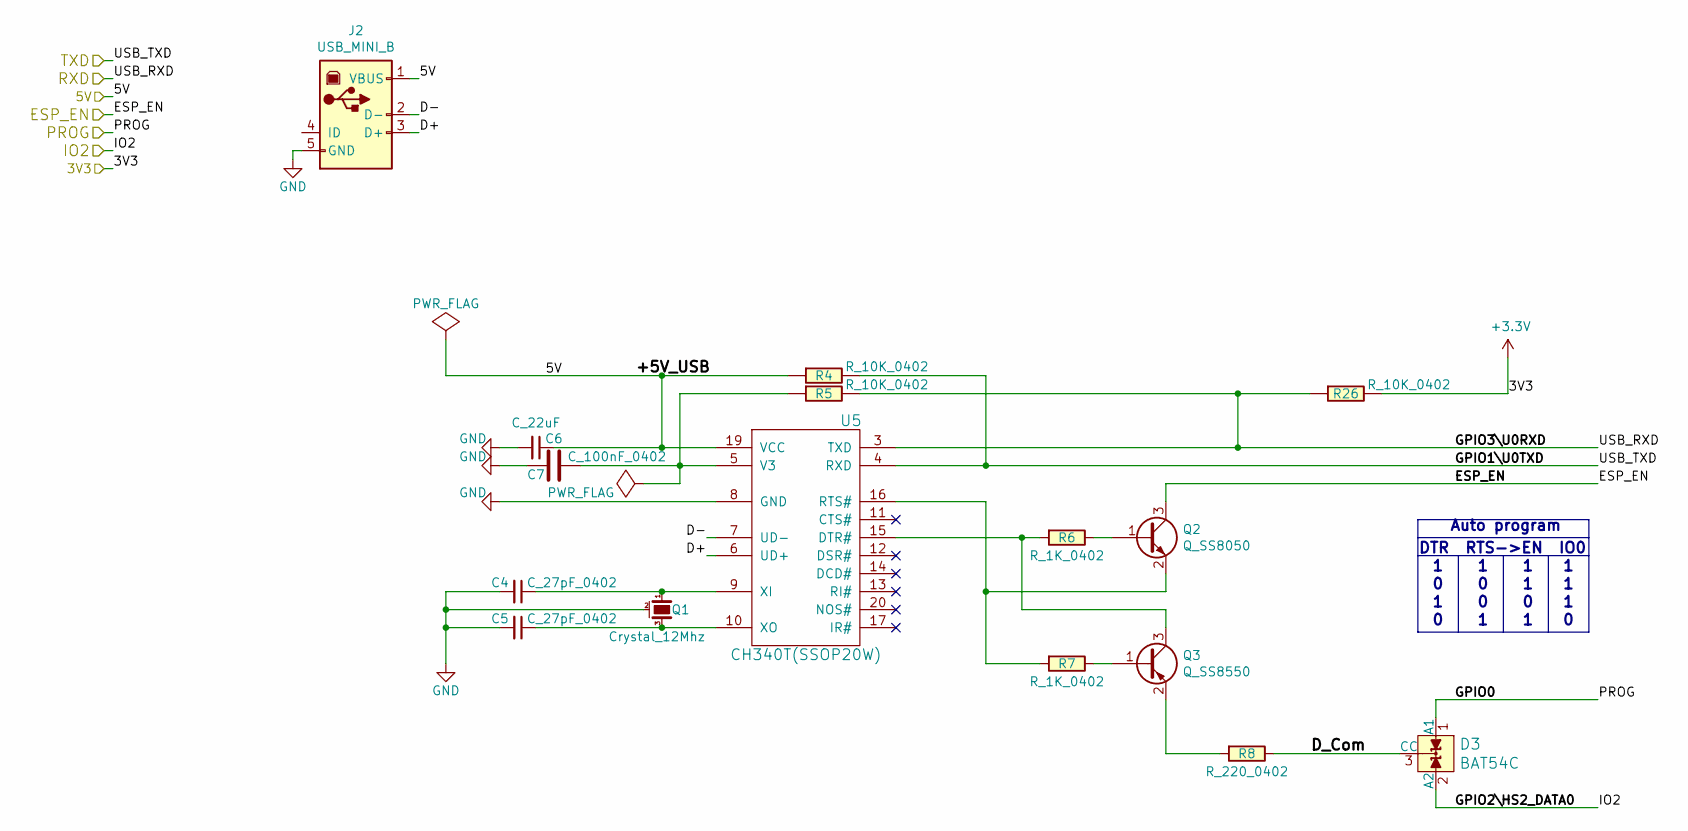
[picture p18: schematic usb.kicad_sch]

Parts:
C4, C5: C_27pF_0402; C_0402_1005Metric_Pad0.74x0.62mm_HandSolder; Part Number 0402CG270J500NTN; LCSC C1557
C6: C_22uF; C_0603_1608Metric_Pad1.08x0.95mm_HandSolder; Part Number CL10A226MQ8NRNC; LCSC C59461
C7: C_100nF_0402; C_0402_1005Metric_Pad0.74x0.62mm_HandSolder; Part Number CL05B104KO5NNNC; LCSC C1525
D3: BAT54C; SOT-23; Part Number LBAT54CLT1G; LCSC C49991
J2: USB_MINI_B; USB-mini-B-0548190519; Part Number 0548190519
Q1: Crystal_12Mhz; Crystal_SMD_3225-4Pin_3.2x2.5mm; Part Number X322512MSB4SI; LCSC C9002
Q2: Q_SS8050; SOT-23; Part Number SS8050; LCSC C2150
Q3: Q_SS8550; SOT-23; Part Number SS8550; LCSC C8542
R4, R5, R26: R_10K_0402; R_0402_1005Metric_Pad0.72x0.64mm_HandSolder; Part Number 0402WGF1002TCE; LCSC C25744
R6, R7: R_1K_0402; R_0402_1005Metric_Pad0.72x0.64mm_HandSolder; Part Number 0402WGF1001TCE; LCSC C11702
R8: R_220_0402; R_0402_1005Metric_Pad0.72x0.64mm_HandSolder; Part Number 0402WGF2200TCE; LCSC C25091
U5: CH340T(SSOP20W); SSOP-20W; Part Number CH340T; LCSC C8689

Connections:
+3V3: R26.2; also elsewhere on the board
/5V: C6.1, J2.1 (VBUS), R4.1, U5.19 (VCC); also elsewhere on the board
/ESP_EN: Q2.3 (C); also elsewhere on the board
/IO2: D3.2 (A2); also elsewhere on the board
/PROG: D3.1 (A1); also elsewhere on the board
/RX: R5.2, R26.1, U5.3 (TXD); also elsewhere on the board
/TX: R4.2, U5.4 (RXD); also elsewhere on the board
/USB/D+: J2.3 (D+), U5.6 (UD+)
/USB/D-: J2.2 (D-), U5.7 (UD-)
/USB/D_Com: D3.3 (CC), R8.1
GND: C4.2, C5.2, C6.2, C7.2, J2.5 (GND), Q1.2 (case), Q1.4 (case), U5.8 (GND); also elsewhere on the board
unnamed: C4.1, Q1.1, U5.9 (XI)
unnamed: C5.1, Q1.3, U5.10 (XO)
unnamed: C7.1, R5.1, U5.5 (V3)
unnamed: Q2.1 (B), R6.1
unnamed: Q2.2 (E), R7.2, U5.16 (RTS#)
unnamed: Q3.1 (B), R7.1
unnamed: Q3.2 (E), R8.2
unnamed: Q3.3 (C), R6.2, U5.15 (DTR#)

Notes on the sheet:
Auto program
DTR RTS->EN IO0

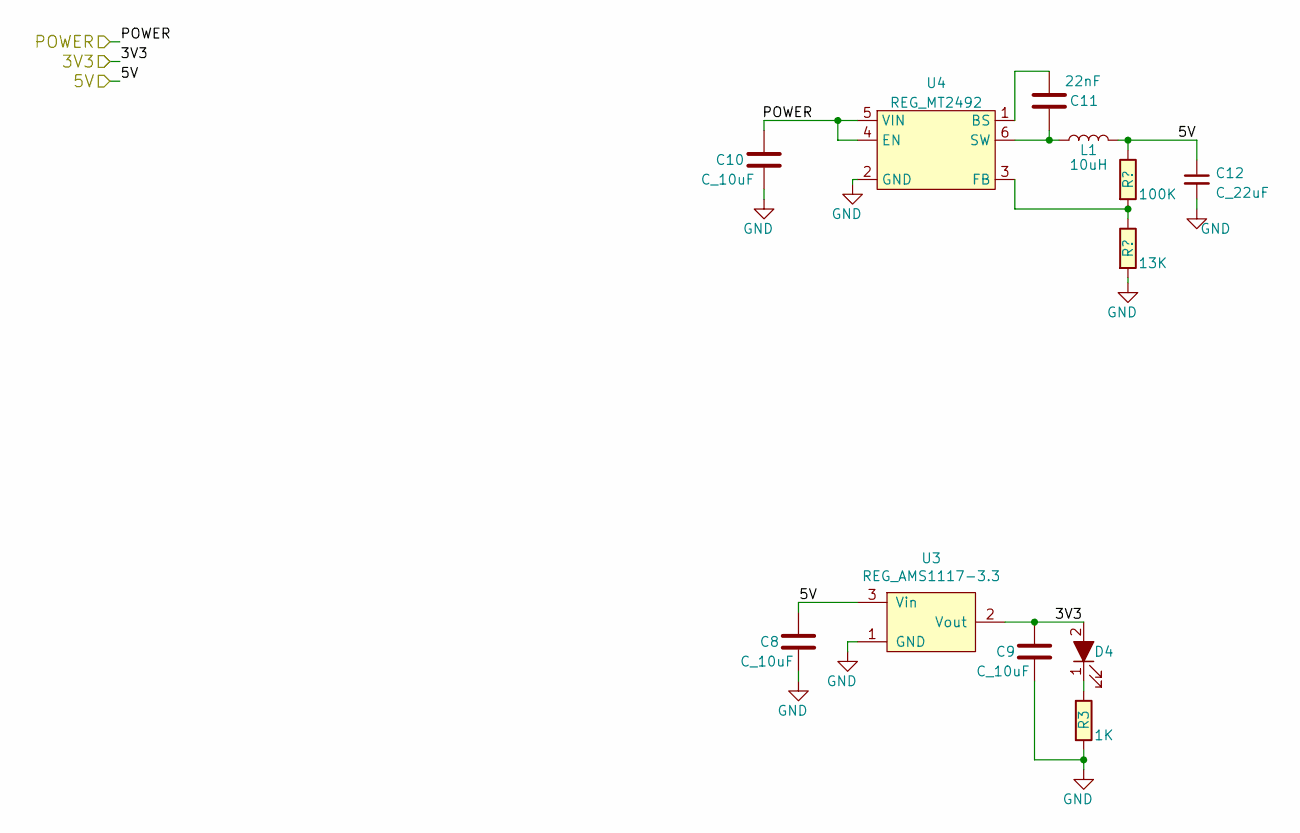
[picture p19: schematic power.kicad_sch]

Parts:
C8, C9, C10: C_10uF; C_0805_2012Metric_Pad1.18x1.45mm_HandSolder; Part Number CL21A106KAYNNNE; LCSC C15850
C11: 22nF; C_0402_1005Metric; Part Number 0402B223K500NT; LCSC C1532
C12: C_22uF; C_0603_1608Metric_Pad1.08x0.95mm_HandSolder; Part Number CL10A226MQ8NRNC; LCSC C59461
D4: LED_G; LED_0603_1608Metric_Pad1.05x0.95mm_HandSolder; Part Number 19-217/BHC-ZL1M2RY/3T; LCSC C72041
L1: 10uH; L_4x4; Part Number WPN4020H100MT; LCSC C98364
R3: 1K; R_0402_1005Metric_Pad0.72x0.64mm_HandSolder; Part Number 0402WGF1001TCE; LCSC C11702
U3: REG_AMS1117-3.3; SOT-223-3_TabPin2; Part Number AMS1117-3.3; LCSC C347222
U4: REG_MT2492; SOT-23-6_Handsoldering; Part Number MT2492; LCSC C89358

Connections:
+3V3: C9.1, D4.2 (A), U3.2 (Vout); also elsewhere on the board
/5V: C8.1, C12.1, L1.2, U3.3 (Vin); also elsewhere on the board
/POWER: C10.1, U4.4 (EN), U4.5 (VIN); also elsewhere on the board
GND: C8.2, C9.2, C10.2, C12.2, R3.2, U3.1 (GND), U4.2 (GND); also elsewhere on the board
unnamed: C11.1, U4.1 (BS)
unnamed: C11.2, L1.1, U4.6 (SW)
unnamed: D4.1 (K), R3.1
unnamed 70: U4.3 (FB); also elsewhere on the board

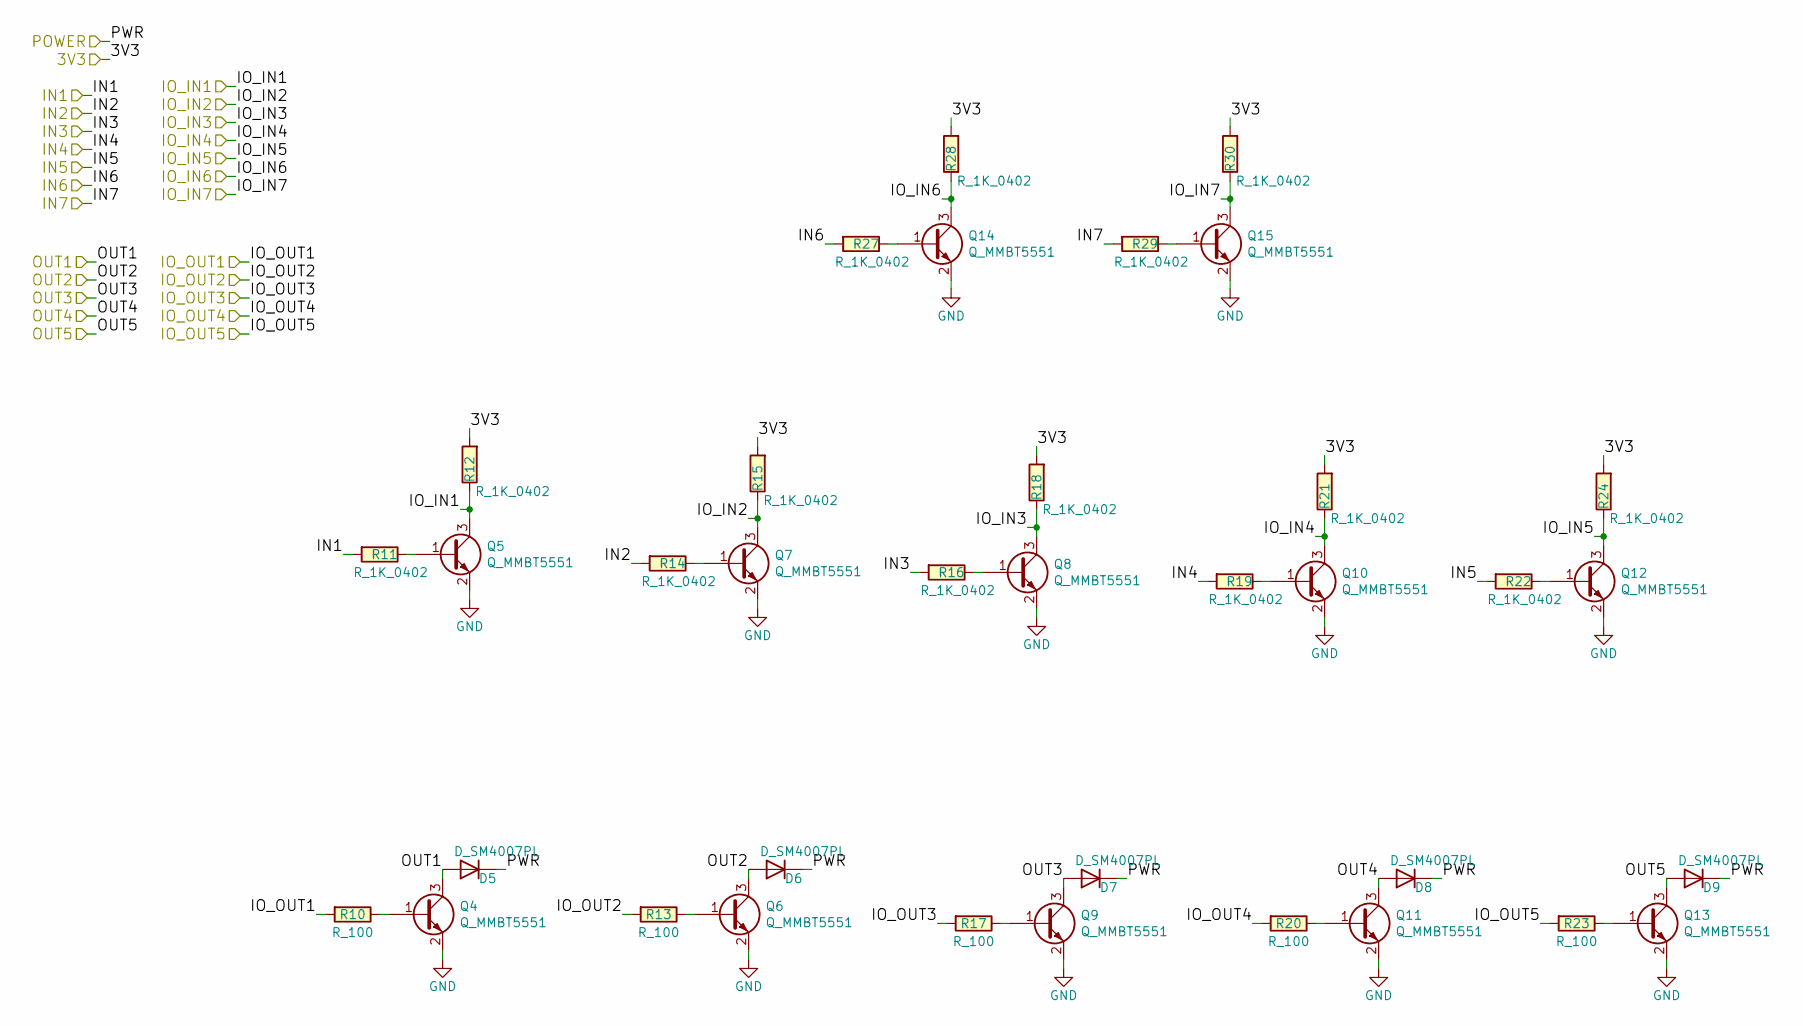
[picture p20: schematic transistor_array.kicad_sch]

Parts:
D5, D6, D7, D8, D9: D_SM4007PL; D_SOD-123F; Part Number SM4007PL; LCSC C64898
Q4, Q5, Q6, Q7, Q8, Q9, Q10, Q11, Q12, Q13, Q14, Q15: Q_MMBT5551; SOT-23; Part Number MMBT5551; LCSC C2145
R10, R13, R17, R20, R23: R_100; R_0402_1005Metric_Pad0.72x0.64mm_HandSolder; Part Number 0402WGF1000TCE; LCSC C25076
R11, R12, R14, R15, R16, R18, R19, R21, R22, R24, R27, R28, R29, R30: R_1K_0402; R_0402_1005Metric_Pad0.72x0.64mm_HandSolder; Part Number 0402WGF1001TCE; LCSC C11702

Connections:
+3V3: R12.2, R15.2, R18.2, R21.2, R24.2, R28.2, R30.2; also elsewhere on the board
/AUX: D9.2 (A), Q13.3 (C); also elsewhere on the board
/AUX_IO: R23.1; also elsewhere on the board
/BUZZER1: D8.2 (A), Q11.3 (C); also elsewhere on the board
/BUZZER1_IO: R20.1; also elsewhere on the board
/CONTACT1: R14.2; also elsewhere on the board
/CONTACT1_IO: Q7.3 (C), R15.1; also elsewhere on the board
/CONTACT2: R16.2; also elsewhere on the board
/CONTACT2_IO: Q8.3 (C), R18.1; also elsewhere on the board
/EXIT: R11.2; also elsewhere on the board
/EXIT_IO: Q5.3 (C), R12.1; also elsewhere on the board
/KEYPAD_PUSH: D7.2 (A), Q9.3 (C); also elsewhere on the board
/KEYPAD_PUSH_IO: R17.1; also elsewhere on the board
/LOCK1: D5.2 (A), Q4.3 (C); also elsewhere on the board
/LOCK1_IO: R10.1; also elsewhere on the board
/LOCK1_STATE: R19.2; also elsewhere on the board
/LOCK1_STATE_IO: Q10.3 (C), R21.1; also elsewhere on the board
/LOCK2: D6.2 (A), Q6.3 (C); also elsewhere on the board
/LOCK2_IO: R13.1; also elsewhere on the board
/LOCK2_STATE: R22.2; also elsewhere on the board
/LOCK2_STATE_IO: Q12.3 (C), R24.1; also elsewhere on the board
/POWER: D5.1 (K), D6.1 (K), D7.1 (K), D8.1 (K), D9.1 (K); also elsewhere on the board
/WG_D0: R27.2; also elsewhere on the board
/WG_D0_IO: Q14.3 (C), R28.1; also elsewhere on the board
/WG_D1: R29.2; also elsewhere on the board
/WG_D1_IO: Q15.3 (C), R30.1; also elsewhere on the board
GND: Q4.2 (E), Q5.2 (E), Q6.2 (E), Q7.2 (E), Q8.2 (E), Q9.2 (E), Q10.2 (E), Q11.2 (E), Q12.2 (E), Q13.2 (E), Q14.2 (E), Q15.2 (E); also elsewhere on the board
unnamed: Q4.1 (B), R10.2
unnamed: Q5.1 (B), R11.1
unnamed: Q6.1 (B), R13.2
unnamed: Q7.1 (B), R14.1
unnamed: Q8.1 (B), R16.1
unnamed: Q9.1 (B), R17.2
unnamed: Q10.1 (B), R19.1
unnamed: Q11.1 (B), R20.2
unnamed: Q12.1 (B), R22.1
unnamed: Q13.1 (B), R23.2
unnamed: Q14.1 (B), R27.1
unnamed: Q15.1 (B), R29.1

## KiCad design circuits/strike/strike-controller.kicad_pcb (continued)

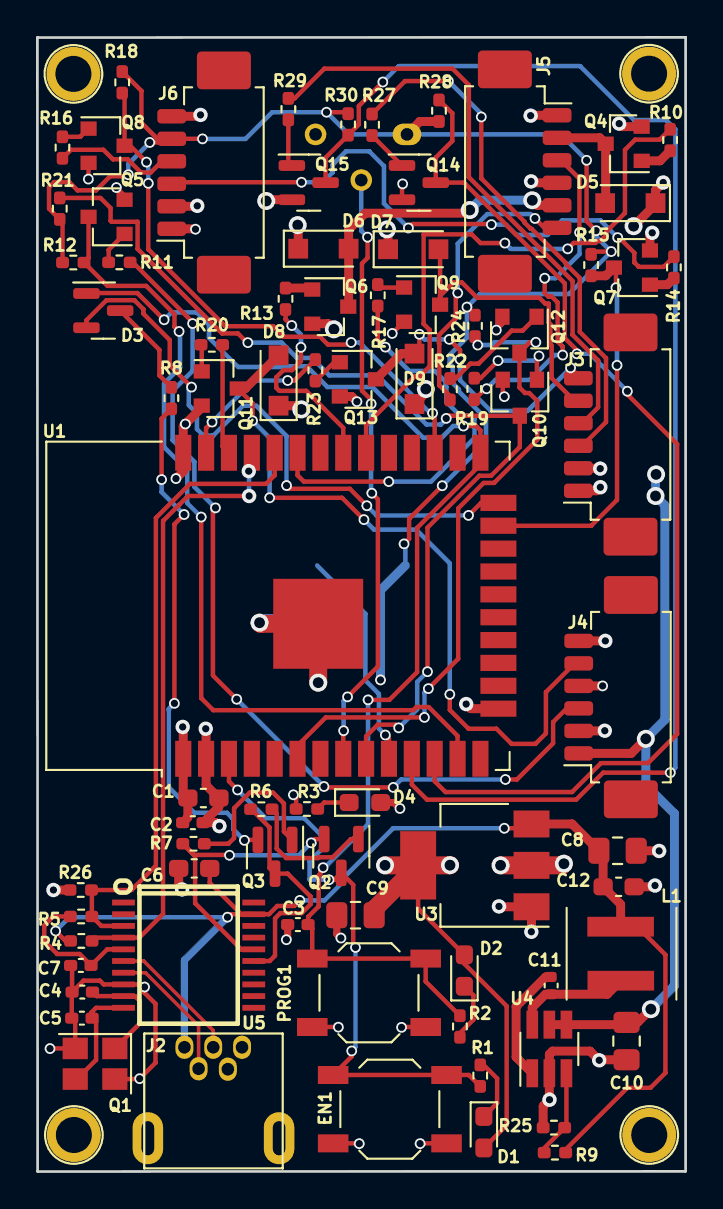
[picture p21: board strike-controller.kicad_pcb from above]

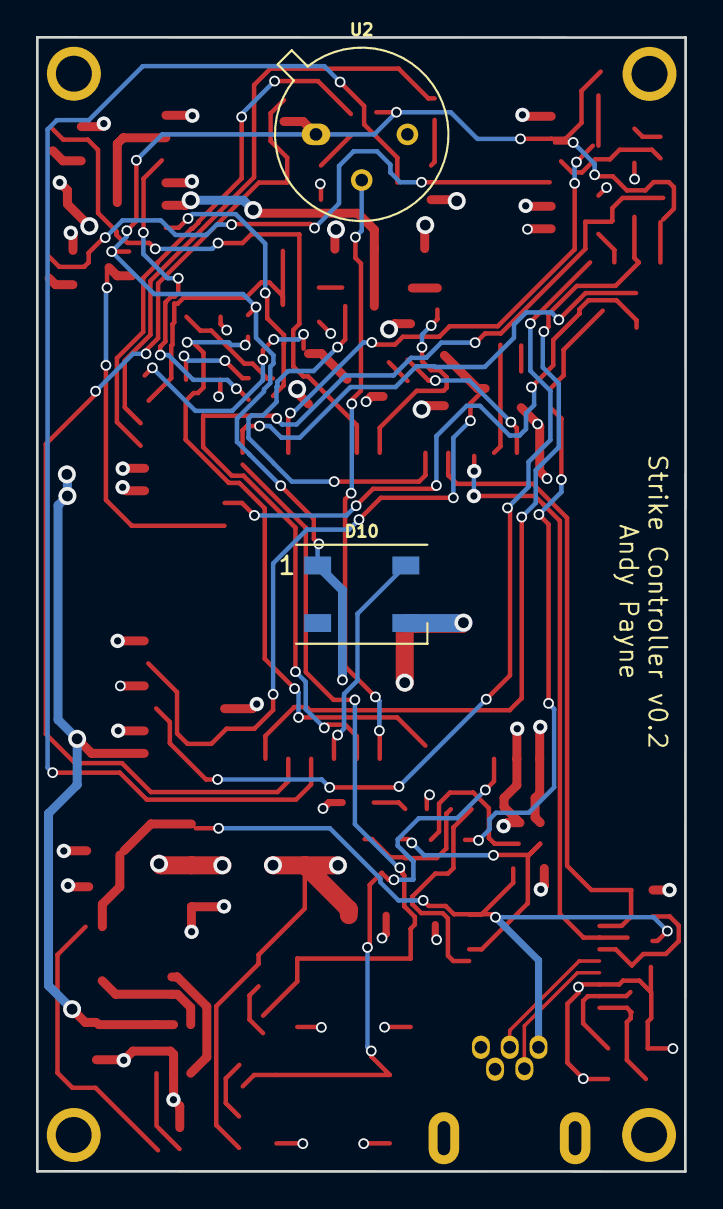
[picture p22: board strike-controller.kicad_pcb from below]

Board: 4 copper layers, 36.0 x 63.0 mm, 84 parts (2 on the bottom side), 64 nets.

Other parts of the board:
C3: C_1uF; C_0402_1005Metric_Pad0.74x0.62mm_HandSolder
R9: 49.9K; R_0402_1005Metric_Pad0.72x0.64mm_HandSolder
R25: 19K; R_0402_1005Metric_Pad0.72x0.64mm_HandSolder

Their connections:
/5V: R9.1; also elsewhere on the board
/PROG: C3.1; also elsewhere on the board
GND: C3.2, R25.2; also elsewhere on the board
unnamed 70: R9.2, R25.1; also elsewhere on the board

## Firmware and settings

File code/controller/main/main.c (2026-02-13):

// main.c

#include "esp_https_ota.h"
#include "esp_event.h"
#include "automation.h"
#include "automation.c"
#include "services/station.c"
#include "services/drivers/i2c.c"
#include "services/drivers/mcp23x17.c"
#include "services/gpio.c"
#include "services/store.c"
#include "services/wiegand_registry.c"
#include "services/authorize.c"
#include "services/buzzer.c"
#include "services/lock.c"
#include "services/wiegand.c"
#include "services/exit.c"
#include "services/motion.c"
#include "services/keypad.c"
#include "services/fob.c"
#include "services/rf_registry.c"
#include "services/rf_receiver.c"
#include "services/server.c"
#include "services/tunnel.c"
#include "services/ap.c"
#include "services/api.c"
#include "esp_http_client.h"
#include "esp_random.h"
#include "esp_heap_caps.h"

#include <stdio.h>
#include <string.h>
#include <ctype.h>
#include "freertos/FreeRTOS.h"
#include "freertos/task.h"
#include "freertos/queue.h"
#include "driver/gpio.h"
#include "esp_log.h"
#include "esp_system.h"
#include "nvs_flash.h"
#include "nvs.h"
#include "esp_wifi.h"
#include "esp_event.h"
#include "esp_vfs_fat.h"
#include "esp_spiffs.h"
#include <time.h>
#include "cJSON.h"
#include "esp_timer.h"

char stored_firmware_md5[33];
bool need_to_update_firmware = true;

static void generate_uuid_v4(char *uuid, size_t size) {
    if (!uuid || size < 37) {
        if (uuid && size > 0) {
            uuid[0] = '\0';
        }
        return;
    }

    uint8_t bytes[16];
    for (int i = 0; i < 16; i += 4) {
        uint32_t value = esp_random();
        bytes[i] = (value >> 24) & 0xFF;
        bytes[i + 1] = (value >> 16) & 0xFF;
        bytes[i + 2] = (value >> 8) & 0xFF;
        bytes[i + 3] = value & 0xFF;
    }

    bytes[6] = (bytes[6] & 0x0F) | 0x40; // Version 4
    bytes[8] = (bytes[8] & 0x3F) | 0x80; // RFC 4122 variant

    snprintf(uuid, size,
             "%02x%02x%02x%02x-%02x%02x-%02x%02x-%02x%02x-%02x%02x%02x%02x%02x%02x",
             bytes[0], bytes[1], bytes[2], bytes[3],
             bytes[4], bytes[5],
             bytes[6], bytes[7],
             bytes[8], bytes[9],
             bytes[10], bytes[11], bytes[12], bytes[13], bytes[14], bytes[15]);
}

static void ensure_device_identity(void) {
    char *stored_device_id = get_char("device_id");
    bool need_new_device_id = true;
    if (stored_device_id && stored_device_id[0] != '\0') {
        size_t len = strlen(stored_device_id);
        need_new_device_id = len < 8; // basic sanity check
    }

    if (need_new_device_id) {
        generate_uuid_v4(device_id, sizeof(device_id));
        if (store_char("device_id", device_id) != ESP_OK) {
            ESP_LOGE(TAG, "Failed to persist device UUID");
        }
        ESP_LOGI(TAG, "Generated new device UUID: %s", device_id);
    } else {
        strncpy(device_id, stored_device_id, sizeof(device_id) - 1);
        device_id[sizeof(device_id) - 1] = '\0';
    }

    if (stored_device_id) {
        free(stored_device_id);
    }

    char *stored_token = get_char("token");
    if (stored_token && stored_token[0] != '\0') {
        strncpy(token, stored_token, sizeof(token) - 1);
        token[sizeof(token) - 1] = '\0';
    } else {
        strncpy(token, device_id, sizeof(token) - 1);
        token[sizeof(token) - 1] = '\0';
        if (store_char("token", token) != ESP_OK) {
            ESP_LOGE(TAG, "Failed to persist token");
        }
        ESP_LOGI(TAG, "Token not found; defaulting to device UUID");
    }

    if (stored_token) {
        free(stored_token);
    }
}

void generate_ssid_from_device_id(char *device_id, char *ssid, size_t size) {
    char suffix[5] = "uuid";
    if (device_id && device_id[0] != '\0') {
        int count = 0;
        for (int i = (int)strlen(device_id) - 1; i >= 0 && count < 4; --i) {
            if (device_id[i] == '-') {
                continue;
            }
            suffix[3 - count] = (char)tolower((unsigned char)device_id[i]);
            count++;
        }
    }

    snprintf(ssid, size, "ac_%s", suffix);
}

void perform_ota_update(const char *ota_url) {
    esp_http_client_config_t http_config = {
        .url = ota_url,
    };

    esp_https_ota_config_t ota_config = {
        .http_config = &http_config,
    };

    esp_err_t ret = esp_https_ota(&ota_config);
    if (ret == ESP_OK) {
        esp_restart();
    } else {
        ESP_LOGE(TAG, "Firmware upgrade failed");
    }
}

esp_err_t http_event_handle(esp_http_client_event_t *evt) {
    switch (evt->event_id) {
        case HTTP_EVENT_ON_DATA:
            if (strcmp((char*)evt->data, stored_firmware_md5) != 0) {
                need_to_update_firmware = true;
            }
            break;
        default:
            break;
    }
    return ESP_OK;
}

void fetch_firmware_md5_from_server(char *buffer, size_t buffer_size, const char *server_ip, const char *server_port) {
    esp_http_client_config_t http_config = {
        .url = NULL,
    };

    char url[256];
    snprintf(url, sizeof(url), "http://%s:%s/firmware-md5", server_ip, server_port);
    http_config.url = url;

    esp_http_client_handle_t client = esp_http_client_init(&http_config);
    
    esp_err_t err = esp_http_client_perform(client);
    if (err == ESP_OK) {
        ESP_LOGI(TAG, "HTTPS Status = %d", esp_http_client_get_status_code(client));
        
        int read_len = esp_http_client_read(client, buffer, buffer_size - 1);
        if (read_len <= 0) {
            // Handle the error, maybe set buffer to an empty string or a known value.
            buffer[0] = '\0';
            ESP_LOGE(TAG, "Failed to read response or response is empty");
        } else {
            buffer[read_len] = '\0'; // Null-terminate the buffer
        }
    } else {
        ESP_LOGE(TAG, "HTTP GET request failed: %s", esp_err_to_name(err));
    }
    
    esp_http_client_cleanup(client);
}


void app_main(void) {
    ESP_ERROR_CHECK(esp_netif_init());
    ESP_ERROR_CHECK(esp_event_loop_create_default());

    // Initialize NVS
    esp_err_t ret = nvs_flash_init();
    if (ret == ESP_ERR_NVS_NO_FREE_PAGES || ret == ESP_ERR_NVS_NEW_VERSION_FOUND)
    {
        ESP_ERROR_CHECK(nvs_flash_erase());
        ret = nvs_flash_init();
    }
    ESP_ERROR_CHECK(ret);

    init_automation_queues();
    automation_log_boot_event();

    ensure_device_identity();
    ESP_LOGI(TAG, "Device UUID: %s", device_id);
    
    char wifi_ssid[32];
    char wifi_password[64];
    snprintf(wifi_ssid, sizeof(wifi_ssid), "pyfitech");
    snprintf(wifi_password, sizeof(wifi_password), "pyfitech");

    load_wifi_credentials_from_flash(wifi_ssid, wifi_password);
    
    // Check if we have valid credentials before attempting station mode
    bool has_valid_credentials = (strlen(wifi_ssid) > 0 && strlen(wifi_password) > 0);
    ESP_LOGI(TAG, "WiFi credentials check: SSID='%s' (len=%d), Password='%s' (len=%d)", 
             wifi_ssid, (int)strlen(wifi_ssid), wifi_password, (int)strlen(wifi_password));
    
    if (has_valid_credentials && station_main(wifi_ssid, wifi_password)) {
        ESP_LOGI(TAG, "Successfully connected to WiFi in station mode");
        load_server_info_from_flash(server_ip, server_port);
        char ota_url[256];

        get_md5_from_flash(stored_firmware_md5, sizeof(stored_firmware_md5));
        // Fetch the latest firmware MD5 hash from the server
        char latest_firmware_md5[33];
        fetch_firmware_md5_from_server(latest_firmware_md5, sizeof(latest_firmware_md5), server_ip, server_port);

        snprintf(ota_url, sizeof(ota_url), "http://%s:%s/firmware.bin", server_ip, server_port);
        // Compare the latest firmware MD5 hash with the stored one
        need_to_update_firmware = strcmp(stored_firmware_md5, latest_firmware_md5) != 0;

        if (need_to_update_firmware) {
            perform_ota_update(ota_url);
        }

        if (strcmp(device_id, "") == 0) {
            ESP_LOGE(TAG, "Device ID not found");
        }

        tunnel_start();
    } else {
        ESP_LOGI(TAG, "Starting Access Point...");
        automation_record_log("WiFi STA failed after retries; starting AP mode");
        
        char ap_ssid[32];
        generate_ssid_from_device_id(device_id, ap_ssid, sizeof(ap_ssid));
        
        ap_main(ap_ssid, "pyfitech");
    }

    gpio_main();
    i2c_main();
    mcp23x17_main();
    auth_main();
    buzzer_main();
    wiegand_registry_init();
    wiegand_main();
    exit_main();
    motion_main();
    keypad_main();
    fob_main();
    rf_registry_init();
    rf_receiver_init();
    lock_main();
    server_main();

    if (initialize_spiffs() == ESP_OK) {
        ESP_LOGI(TAG, "SPIFFS Initialized successfully");
    }
    send_user_count();

    int cnt = 0;
    while (1) {
        // Get system information
        int64_t uptime_us = esp_timer_get_time();
        int64_t uptime_s = uptime_us / 1000000;
        int days = uptime_s / (24 * 3600);
        uptime_s %= (24 * 3600);
        int hours = uptime_s / 3600;
        uptime_s %= 3600;
        int minutes = uptime_s / 60;
        int seconds = uptime_s % 60;

        size_t current_free_heap = esp_get_free_heap_size();
        size_t min_free_heap = esp_get_minimum_free_heap_size();
        size_t largest_free_block = heap_caps_get_largest_free_block(MALLOC_CAP_8BIT);

        // Get NVS stats for the 'nvs' partition
        nvs_stats_t nvs_stats;
        esp_err_t err = nvs_get_stats("nvs", &nvs_stats);
        if (err != ESP_OK) {
            ESP_LOGE(TAG, "Failed to get NVS stats (%s)", esp_err_to_name(err));
        }

        // Log system status
        ESP_LOGI(TAG, "------ SYSTEM STATUS ------");
        ESP_LOGI(TAG, "Uptime: %d days %d hours %d minutes %d seconds", days, hours, minutes, seconds);
        ESP_LOGI(TAG, "Free Heap: %zu bytes (min: %zu, largest block: %zu)", current_free_heap, min_free_heap, largest_free_block);
        ESP_LOGI(TAG, "NVS Free Entries: %u", nvs_stats.free_entries);
        ESP_LOGI(TAG, "NVS Used Entries: %u", nvs_stats.used_entries);
        ESP_LOGI(TAG, "Loop Count: %d", cnt++);
        ESP_LOGI(TAG, "----------------------------");

        vTaskDelay(60 * 1000 / portTICK_PERIOD_MS);
    }
}

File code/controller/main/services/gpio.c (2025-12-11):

#include <stdio.h>
#include <stdlib.h>
#include "freertos/FreeRTOS.h"
#include "freertos/task.h"
#include "freertos/queue.h"
#include "driver/gpio.h"

#define MCP_INTA_GPIO 	34
#define MCP_INTB_GPIO 	35

// Onboard IO (direct ESP32 pins)
// NOTE: In the current hardware revision most door/lock IO is handled via the MCP23017.
// These direct GPIO assignments are largely unused when USE_MCP23017 == 1, but we keep
// them defined for compatibility.
#define BUZZER_IO        2
#define CONTACT_IO_1     3
#define CONTACT_IO_2     22   // moved off low GPIOs to free 4–7 for Wiegand
#define LOCK_IO_1        23
#define LOCK_IO_2        24
#define EXIT_BUTTON_IO_1 25
#define EXIT_BUTTON_IO_2 26
#define FOB_IO_1         9
#define FOB_IO_2         10
#define RADAR_BUTTON_IO_1 11
#define RADAR_BUTTON_IO_2 12
#define KEYPAD_IO_1      15 
#define KEYPAD_IO_2      16 

// Wiegand definitions
// Board routing: ESP32-S3 module pins 4,5,6,7 carry the four Wiegand DATA lines.
// These correspond to GPIO4–GPIO7.
#define WG0_DATA0_IO     4   // Channel 0, DATA0
#define WG0_DATA1_IO     5   // Channel 0, DATA1
#define WG1_DATA0_IO     6   // Channel 1, DATA0
#define WG1_DATA1_IO     7   // Channel 1, DATA1
#define OPEN_IO_1 21
#define SIGNAL_IO_1 15
#define SIGNAL_IO_2 16

// Configure only the pins we actually use on the ESP32 directly.
// Door/lock/keypad/contact IO is handled via MCP23017 when USE_MCP23017 == 1.
#define GPIO_OUTPUT_PIN_SEL  ((1ULL<<BUZZER_IO) | (1ULL<<OPEN_IO_1))
// Note: GPIO15 (RF_DATA) is configured separately by rf_receiver.c with its own pull-up
#define GPIO_INPUT_PIN_SEL   ((1ULL<<WG0_DATA0_IO) | (1ULL<<WG0_DATA1_IO) | (1ULL<<WG1_DATA0_IO) | (1ULL<<WG1_DATA1_IO) | (1ULL<<MCP_INTA_GPIO) | (1ULL<<MCP_INTB_GPIO))
#define ESP_INTR_FLAG_DEFAULT 0

void gpio_main(void)
{
    gpio_config_t io_conf;
    io_conf.intr_type = GPIO_INTR_DISABLE;
    io_conf.mode = GPIO_MODE_OUTPUT;
    io_conf.pin_bit_mask = GPIO_OUTPUT_PIN_SEL;
    io_conf.pull_down_en = 0;
    io_conf.pull_up_en = 0;
    gpio_config(&io_conf);

    io_conf.intr_type = GPIO_INTR_ANYEDGE;
    io_conf.pin_bit_mask = GPIO_INPUT_PIN_SEL;
    io_conf.mode = GPIO_MODE_INPUT;
    io_conf.pull_up_en = 1;
    gpio_config(&io_conf);

    gpio_install_isr_service(ESP_INTR_FLAG_DEFAULT);
}

bool get_io (uint8_t io)
{
	bool val = false;
	if (USE_MCP23017) {
		val = get_mcp_io(io);
	} else {
		val = gpio_get_level(io);
		// printf("get_io io:%d\tval: %d\n", io, val);
	}
	return val;
}

void set_io (uint8_t io, bool val)
{
	
	if (USE_MCP23017) {
		// printf("set_mcp_io io:%d\tval: %d\n", io, val);
		set_mcp_io(io, val);
	} else {
		printf("gpio_set_level io:%d\tval: %d\n", io, val);
		gpio_set_level(io, val);
	}
}

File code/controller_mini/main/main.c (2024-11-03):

// main.c

#include "esp_event.h"
#include "nvs_flash.h"
#include "automation.h"
#include "cJSON.h"
#include "services/network_manager.c"  // Import network functionality
#include "services/ota_manager.c"      // Import OTA update functionality
#include "services/service_manager.c"  // Import service management
#include "services/config_manager.c"   // Import configuration management
#include "services/store.c"
#include "services/ws_client.c"
#include "services/utilities.c"

const char *TAG = "open-automation";

void app_main(void) {
    // Load device and network configurations
    char device_id[64] = {0};
    char token[600] = {0};
    char wifi_ssid[32] = {0};
    char wifi_password[64] = {0};
    char server_ip[64] = {0};
    char server_port[6] = {0};

    // Initialize NVS
    ESP_ERROR_CHECK(nvs_flash_init());
    ESP_ERROR_CHECK(esp_netif_init());
    ESP_ERROR_CHECK(esp_event_loop_create_default());
    
    load_device_settings(device_id, sizeof(device_id), token, sizeof(token));
    ESP_LOGI(TAG, "Device ID after load: %s", device_id);
    ESP_LOGI(TAG, "Token after load: %s", token);

    load_wifi_credentials(wifi_ssid, wifi_password, sizeof(wifi_ssid), sizeof(wifi_password));
    load_server_info_from_flash(server_ip, server_port);

    automationInit();

    // Network setup and decision making
    network_manager_init(device_id, wifi_ssid, wifi_password, "pyfitech");

    if (network_is_connected()) {
        ota_manager_check_update();  // Check for firmware updates
        service_manager_start_all(); // Start all peripheral services
        ws_client_main(server_ip, server_port, device_id, token);  // WebSocket and other server interactions
    } else {
        ap_main(device_id, "pyfitech"); // Handle AP mode if not connected to a station
        ota_manager_check_update();     // Check for firmware updates
        service_manager_start_all();    // Start all peripheral services
    }

    ESP_LOGI(TAG, "Monitoring system status...");
    while (1) {
        monitor_system_status();
        vTaskDelay(10 * 1000 / portTICK_PERIOD_MS);
    }
}

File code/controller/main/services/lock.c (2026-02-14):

#include <stdio.h>
#include <string.h>
#include "freertos/FreeRTOS.h"
#include "freertos/task.h"
#include "esp_log.h"
#include "cJSON.h"
#include "automation.h"
#include "esp_timer.h"

// Function declarations
bool get_io(uint8_t io);
void set_io(uint8_t io, bool val);
void set_mcp_io_dir(uint8_t io, bool dir);
void set_mcp_io(uint8_t io, bool val);
bool get_mcp_io(uint8_t io);
void set_bool(const char *key, bool value);
bool get_bool(const char *key, bool default_value);
void beep(int cnt);
void longBeep(int cnt);
bool wiegand_pin_entry_active(int channel);

// MCP definitions
#define MCP_OUTPUT 0
#define MCP_INPUT  1

// MCP pin definitions
#define MCP_A0  0
#define MCP_A1  1
#define MCP_A2  2
#define MCP_A3  3
#define MCP_A4  4
#define MCP_A5  5
#define MCP_A6  6
#define MCP_A7  7
#define MCP_B0  8
#define MCP_B1  9
#define MCP_B2  10
#define MCP_B3  11
#define MCP_B4  12
#define MCP_B5  13
#define MCP_B6  14
#define MCP_B7  15

#define LOCK_MCP_IO_1       MCP_A0
#define LOCK_MCP_IO_2       MCP_B0
#define NUM_OF_LOCKS        2

/* Channel 1 = LOCK0: GPA1=SENSE, GPA2=CLOSE_IO. Channel 2 = LOCK1: GPB1=SENSE, GPB2=CLOSE_IO */
const uint8_t LOCK_CONTACT_PIN_1 = A2;  /* LOCK0_CLOSE_IO (GPA2) */
const uint8_t LOCK_CONTACT_PIN_2 = B2;  /* LOCK1_CLOSE_IO (GPB2) */

const uint8_t LOCK_SIGNAL_PIN_1 = A1;   /* LOCK0_SENSE (GPA1) */
const uint8_t LOCK_SIGNAL_PIN_2 = B1;   /* LOCK1_SENSE (GPB1) */

bool ARM = false;
bool ALERT = true;
char lock_service_message[1000];
bool lock_service_message_ready = false;
int relock_delay = 2 * 1000;
int button_disabled = false;
cJSON *lock_payload = NULL;
int LOCK_DEBOUNCE_DELAY = 5;
bool lock_contact_timer_1_expired = true;
int lock_count = 0;

typedef struct {
    uint8_t controlPin;
    uint8_t contactPin;
	uint8_t signalPin;
    uint8_t channel;
    bool isContact;
    bool prevIsContact;
	bool shouldLock;
    bool isLocked;
	bool isSignal;
    bool pulse;
    bool polarity;
    bool expired;
    bool enable;
    bool enableContactAlert;
    int delay;
    int count;
    bool alert;
	bool sentSignalAlert;
	bool sentContactAlert;
    cJSON *payload;
    char settings[200];
    char key[50];
    char type[40];
} Lock;

Lock locks[NUM_OF_LOCKS];

static char s_last_action_source[12] = "sys";

void lock_set_action_source(const char *source) {
    const char *fallback = "sys";
    if (!source || source[0] == '\0') {
        source = fallback;
    }
    strlcpy(s_last_action_source, source, sizeof(s_last_action_source));
}

void start_lock_contact_timer(Lock *lck, bool val) {
    lck->expired = !val;
    if (!val) {
        lck->count = 0;
    }
}

void check_lock_contact_timer(Lock *lck) {
	if (!lck->enable) return;
	char log_msg[500];

    if (lck->count >= lck->delay
        && lck->shouldLock
        && (!lck->isSignal || !lck->isContact)
        && lck->enableContactAlert
        && lck->enable
        && !lck->expired)
    {
        if (!lck->isSignal && !lck->sentSignalAlert) {
            snprintf(log_msg, sizeof(log_msg), 
                "{\"event_type\":\"log\",\"payload\":"
                "{\"service_id\":\"ac_1\", "
                "\"type\":\"access-control\", "
                "\"description\":\"No armed status coming from lock.\", "
                "\"event\":\"authentication\", "
                "\"value\":\"true\"}"
                "}");
            addServerMessageToQueue(log_msg);
            lck->sentSignalAlert = true;
        }
        if (!lck->isContact && !lck->sentContactAlert) {
            snprintf(log_msg, sizeof(log_msg), 
                "{\"event_type\":\"log\",\"payload\":"
                "{\"service_id\":\"ac_1\", "
                "\"type\":\"access-control\", "
                "\"description\":\"Door is still open when armed.\", "
                "\"event\":\"authentication\", "
                "\"value\":\"true\"}"
                "}");
            addServerMessageToQueue(log_msg);
            lck->sentContactAlert = true;
        }
        if (!wiegand_pin_entry_active(lck->channel)) {
            beep_keypad(1, lck->channel);
            ESP_LOGI(TAG, "Contact alert beep lock %d (contact=%d signal=%d)",
                     lck->channel,
                     lck->isContact ? 1 : 0,
                     lck->isSignal ? 1 : 0);
        }
    } else {
        lck->sentSignalAlert = false;
        lck->sentContactAlert = false;
        lck->count++;
    }

    // check for contact change and send opened or closed event depending on the contact state
    if (lck->isContact != lck->prevIsContact) {
		if (lck->isContact) {
			snprintf(log_msg, sizeof(log_msg), 
				"{\"event_type\":\"log\",\"payload\":"
				"{\"service_id\":\"ac_1\", "
				"\"type\":\"access-control\", "
				"\"description\":\"Door closed.\", "
				"\"event\":\"authentication\", "
				"\"value\":\"true\"}"
				"}");
			addServerMessageToQueue(log_msg);
			ESP_LOGI(TAG, "Door closed.");
		} else {
			snprintf(log_msg, sizeof(log_msg), 
				"{\"event_type\":\"log\",\"payload\":"
				"{\"service_id\":\"ac_1\", "
				"\"type\":\"access-control\", "
				"\"description\":\"Door opened.\", "
				"\"event\":\"authentication\", "
				"\"value\":\"true\"}"
				"}");
			addServerMessageToQueue(log_msg);
			ESP_LOGI(TAG, "Door opened.");
		}
    }
	lck->prevIsContact = lck->isContact;
}

static void lock_contact_timer(void *pvParameter) {
    while (1) {
        for (int i = 0; i < NUM_OF_LOCKS; i++)
            check_lock_contact_timer(&locks[i]);
        vTaskDelay(1000 / portTICK_PERIOD_MS);
    }
}

void createLockServiceMessage(bool value) {
    snprintf(lock_service_message, sizeof(lock_service_message),
             "{\"event_type\":\"service/state\",\"payload\":{\"service_id\":\"locks[0]\",\"state\":{\"locked\":%s}}}",
             value ? "true" : "false");
    lock_service_message_ready = true;
}

void enableLock(int ch, bool val) {
    for (int i = 0; i < NUM_OF_LOCKS; i++)
        if (locks[i].channel == ch) locks[i].enable = val;
}
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

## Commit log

2019-04-10 Initial commit.
    [InfraRed-2018-05-11-14-06-19.sch, InfraRed.sch, Interface.sch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]
2019-04-16 Investigating flash storage write error
    [main.c]
2019-07-04 starting with standalone system
    [InfraRed-2018-05-11-14-06-19.sch, InfraRed.sch, Interface.sch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]
2019-07-05 finishing up controller model
    [box.blend]
2019-08-02 enabled pullup on relay
2019-08-14 added capacitive touch plate to model
    [box.blend]
2019-08-16 added FOB and Exit Button to gpio
2019-08-30 mad lid for box
    [box.blend, lid.stl]
2019-09-14 added the ability to disable the button through gpio
2019-09-18 added pcb mounts to daughterboard
    [box.blend, box.stl]
2019-09-20 enlarged base to pcb mounts
    [box.blend, box.stl]
2019-10-06 made keypad model, starting code
    [keypad.blend, keypad.stl, nfc.blend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]
2019-10-06 added keypad code
    [box.stl]
2019-10-07 finished keypad driver
2019-10-08 increased pad thickness by 1cm
    [keypad.blend, keypad.stl]
2019-10-30 added program buttons
    [box.blend, box.stl]
2020-12-14 started new controller circuit
    [Adapter-TE-52-B_Cu.gbr, Adapter-TE-52-B_Mask.gbr, Adapter-TE-52-B_Paste.gbr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]
2021-01-03 Sent to fab.
    [Wiegand.sch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]
2021-01-05 Increased min. via size, sent back to fab
    [access-controller-B_Cu.gbr, access-controller-B_Mask.gbr, access-controller-B_Paste.gbr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]
2021-01-06 changed footprint for 0402 resistor array, sent back to fab
    [access-controller-B_Cu.gbr, access-controller-B_Mask.gbr, access-controller-B_Paste.gbr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]
2021-02-22 Code ready for testing on new board. Still working on store/restore settings functions.
    [partitions_example.csv]
2021-03-01 finished schematic corrections, working on layout
    [access-controller.sch, control.sch, ethernet.sch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]
2021-03-03 finished layout, sent to board house
    [access-controller-B_Cu.gbr, access-controller-B_Mask.gbr, access-controller-B_Paste.gbr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]
2021-03-23 got board back from fab, testing
    [poe.sch, power.sch, unselected.xlsx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]
2021-04-05 Organized website interface, added enable/disable of various interface devices, need to test ethernet and fix PoE
    [exit.c, file_server.c, fob.c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]
2021-05-06 modifed PoE circuit
    [control.sch, poe.sch, power.sch]
2021-05-08 create manufacturer files
    [access-controller-B_Cu.gbr, access-controller-B_Mask.gbr, access-controller-B_Paste.gbr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]
2021-06-12 Disable Keypad when fob disarms lock. This is so the keypad does not rearm the lock if used.
    [Keypad_4x4_case.stl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]
2021-08-25 Made structs for actuators.
    [controller-cover.stl, controller.blend]
2022-04-27 made new pcb for controller, added new PoE circuit and ethernet
    [2673627A20220427090037.xlsx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]
2022-04-27 corrected footprints for manufacturer
    [2673627A20220427090037.xlsx, 2673627A20220428025152.xlsx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]
2022-06-09 Finished schematic for shrinking PCB for residential systems
    [2673627A20220428025152.xlsx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]
2022-06-09 added schematic image
2023-02-19 Updated mosfet in PoE circuit, sent to fab - access controller v0.5
    [Adapter-TE-52-B_Cu.gbr, Adapter-TE-52-B_Mask.gbr, Adapter-TE-52-B_Paste.gbr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]
2023-04-03 Linking up to the website!
    [access-controller-B_Cu.gbr, access-controller-B_Mask.gbr, access-controller-B_Paste.gbr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]
2023-09-07 added user management
    [partitions_example.csv]
2023-09-21 cured memory leaks, added device logs, and more...
    [lock.c, main.c, store.c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]
2023-09-23 fixed user mgmt memory leaks, trying to store 1000 users
    [store.c]
2023-09-25 using spiffs to manage users instead of nvs
    [partitions.csv]
2023-10-19 fixed weigand bug
    [partitions.csv]
2023-11-05 fixed build
    [partitions.csv]
2023-12-27 sent to fab! 0.6
    [access-controller-B_Cu.gbr, access-controller-B_Mask.gbr, access-controller-B_Paste.gbr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]
2023-12-28 sent to fab, revised
    [access-controller-B_Cu.gbr, access-controller-B_Mask.gbr, access-controller-B_Paste.gbr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]
2023-12-29 added polarity to speaker, added lcsc part for header
    [access-controller.kicad_pcb, access-controller.kicad_sch]
2024-01-13 powering 5v reg from 12v reg
    [access-controller.kicad_pcb, power.kicad_sch]
2024-01-25 working on esp32s3 upgrade
    [partitions.csv, partitions_example.csv]
2024-01-25 upgrading to esp32s3
2024-08-11 testing radar
    [access-controller-B_Cu.gbr, access-controller-B_Mask.gbr, access-controller-B_Paste.gbr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]
2025-07-31 Enable exit buttons, fobs, and motion sensors by default and add logging for activation events
2025-07-31 Remove deprecated files and refactor project structure for ESP32-S3, including updates to service implementations and configuration files.
    [partitions.csv]
2025-07-31 Remove obsolete files and clean up project structure for ESP32-S3, enhancing maintainability and organization.
    [partitions.csv]
2025-07-31 Refactor message queue handling and improve memory management in automation service. Adjust maximum queue size and enhance error handling for message processing. Implement emergency memory check to c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
    [file_server.c, lock.c, main.c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]
2025-07-31 Refactor automation service to enhance message queue management and memory handling. Introduce mutex for thread safety, increase maximum queue size, and improve error handling for message processing.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
    [buzzer.c, exit.c, fob.c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]
2025-07-31 Refactor automation service to improve message handling and memory management. Update checkServiceMessage functions for better clarity and efficiency, enhance error logging, and ensure proper memory 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
    [buzzer.c, exit.c, fob.c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]
2025-07-31 Enhance WiFi connection handling by validating credentials before attempting station mode. Improve logging for WiFi status and adjust task stack sizes for fob and keypad services. Implement debouncin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
    [fob.c, keypad.c, lock.c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]
2025-07-31 Update exit service to change button pin definitions and enhance logging for button state changes. Improve WebSocket handler with frame length validation and JSON parsing error handling. Add debug lo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
    [exit.c]
2025-07-31 Refactor exit service to simplify button state handling and remove excessive logging. Update keypad pin definitions for improved clarity. Streamline MCP I/O value retrieval by eliminating redundant l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
2025-07-31 Refactor main service files to replace radar service with motion service, enhancing logging for button state changes in exit, fob, and keypad services. Update pin definitions for fob service and impr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
    [exit.c, fob.c, keypad.c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]
2025-07-31 Revert motion service pin definitions to correct values and streamline logging. Remove excessive debug logs in motion checks and configure motion pins as inputs. Enhance clarity in motion detection l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
    [motion.c]
2025-07-31 Add WebSocket message handling for WiFi credentials and improve connection state checks. Implement confirmation message before device restart and enhance error handling in WebSocket communication. Up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
2025-11-04 Update device identity management by implementing UUID generation and ensuring token handling. Refactor WebSocket message processing for improved clarity and error handling. Adjust HTML and JavaScrip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
    [main.c, store.c]
2025-11-04 Add API integration for state management in JavaScript and C services
    - Introduced new API routes for managing lock, exit, and fob states.
    - Refactored JavaScript to replace WebSocket communication with RESTful API calls for state updates and retrieval.
    - Implemented state snapshot functions in C for locks, exits, and fobs to facilitate API responses.
    - Enhanced error handling and user feedback in the JavaScript code for WiFi and server configuration updates.
    - Updated main controller to include new API service for improved modularity and maintainability.
    [exit.c, file_server.c, fob.c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]
2025-11-04 Refactor API calls in JavaScript and enhance device identity handling in C
    - Updated JavaScript to use relative paths for API calls, improving flexibility.
    - Increased the size of the assigned_id buffer in the C tunnel client structure for better identity management.
    - Modified the tunnel main loop to handle device identity more robustly, including logging enhancements.
    - Adjusted the handleDeviceList method in the server to include device URLs in the response for better client integration.
2025-11-07 Remove obsolete access controller lock file and multiple outdated backup zip files. Enhance automation service with improved logging, including a shutdown handler and better memory management for log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
    [access-controller.kicad_pcb, access-controller.kicad_sch, controller.3mf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]
2025-12-11 order from fab
    [access-controller-B_Cu.gbr, access-controller-B_Mask.gbr, access-controller-B_Paste.gbr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]
2025-12-11 Refactor Wi-Fi management and enhance remote FOB configuration
    - Removed obsolete lock files related to the access controller.
    - Introduced new API routes for managing Wi-Fi credentials, including adding, deleting, and connecting to networks.
    - Enhanced the JavaScript interface for Wi-Fi management, allowing users to view saved networks and connect or delete them.
    - Improved remote FOB configuration options, including mode selection, channel masking, exit duration, and alert settings.
    - Updated logging for Wi-Fi connection attempts and added error handling for API interactions.
    [file_server.c, main.c, rf_receiver.c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]
2025-12-27 Refactor Wi-Fi credentials loading and enhance Wiegand frame processing
    - Removed logging of Wi-Fi credentials during loading for improved security.
    - Updated Wiegand handling to only authorize non-empty PINs and improved frame processing logic to prevent data loss.
    - Enhanced logging for frame start and completion to aid in debugging and monitoring.
    [store.c, wiegand.c]
2026-02-09 fixed keypad
    [controller-cover.3mf, controller-cover.stl, controller-plate.3mf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]
2026-02-10 fixed keypad push, inverted io
    [buzzer.c]
